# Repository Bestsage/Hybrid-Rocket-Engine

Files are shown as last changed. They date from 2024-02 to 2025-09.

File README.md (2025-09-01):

# Hybrid Rocket Engine Demonstrator


[]()


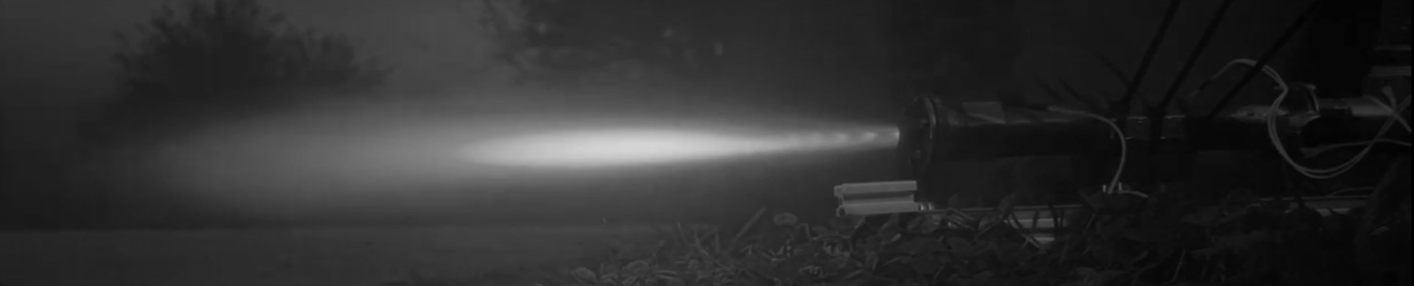
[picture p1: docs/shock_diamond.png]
Test firing with shock diamonds


## Table of Contents
- [Overview](#overview)
- [Abstract](#abstract)
- [Technical Specifications](#technical-specifications)
- [Test Results Gallery](#test-results-gallery)
- [Versioning System](#versioning-system)
- [Key Features](#key-features)
- [Repository Contents](#repository-contents)
- [Safety Considerations](#safety-considerations)
- [How to Use This Repository](#how-to-use-this-repository)
- [Citation](#citation)
- [Authors](#authors)
- [License](#license)

## Overview
This repository documents the **design, construction, and testing** of a **hybrid rocket engine demonstrator**, developed as part of our *Travail de maturité* and presented at the **Swiss National Contest**.  

Hybrid propulsion combines a **liquid oxidizer** with a **solid fuel grain**, offering a **middle ground** between:
- Simplicity and accessibility of **solid rockets**
- Performance and controllability of **bi-liquid engines**

Our objective:  
👉 Build a **reliable, efficient engine** with limited resources, able to theoretically propel a model rocket.

---

## Abstract
Over 9 months, we applied an **iterative engineering process**:  
- **Design**: CAD modeling (Fusion 360), rendering (Blender), combustion simulations (RocketCEA).  
- **Construction**: Machined steel combustion chamber, graphite nozzle, ABS/ASA fuel grains.  
- **Instrumentation**: Custom-built static test bench with Arduino-based data acquisition (thrust, pressure, temperature).  
- **Testing**: 18 static firings, continuously improving injector design, nozzle geometry, and fuel formulation.  

**Results**:  
- Stable thrust plateau of **26 N** (peak **40.4 N**) during 5-second burns  
- Combustion chamber pressure remained constant  
- Temperature < **150 °C** (no thermal risk observed)  
- **16 out of 18 successful tests** → high system reliability  
- Supersonic exhaust confirmed (visible shock diamonds)  

These results confirm that **hybrid propulsion is a viable option for model rocketry**, balancing performance, cost, and safety.

---

## Technical Specifications

### Engine Performance (Latest Configuration: V3-3-1)
| Parameter | Value | Unit |
|---|---|---|
| **Maximum Thrust** | 40.42 | N |
| **Average Thrust** | 26.02 | N |
| **Burn Time** | 5.0 | seconds |
| **Total Impulse** | 130.09 | N⋅s |
| **Specific Impulse** | 38.94 | seconds |
| **Chamber Pressure** | 5.31 (avg), 8.35 (max) | bar |

### Physical Specifications
| Component | Specification |
|---|---|
| **Combustion Chamber** | Machined steel, custom design |
| **Nozzle** | Graphite, throat diameter 5mm, exit 24mm |
| **Fuel Grain** | ABS/ASA plastic, star-shaped geometry |
| **Oxidizer** | Gaseous oxygen at 9 bar |
| **Injector** | Custom 3.5mm diameter orifice |

### Test Configuration
- **Fuel Mass**: 46g initial, 34g consumed (73.9% burn efficiency)
- **O/F Ratio**: 9.0:1 (oxygen to fuel)
- **Operating Temperature**: <150°C (safe thermal limits)
- **Success Rate**: 89% (16/18 successful tests)

---

## Test Results Gallery

### Performance Data by Version
- **[Version 1 Tests](docs/v1/)** - Initial proof of concept
- **[Version 2 Tests](docs/v2/)** - Improved injector design  
- **[Version 3 Tests](docs/v3/)** - Optimized nozzle geometry

### Key Test Results
| Test ID | Thrust (N) | Burn Time (s) | Chamber Pressure (bar) | Status |
|---|---|---|---|---|
| V3-1-1 | 10.65 peak | 5.0 | 6.76 max | ✅ Success |
| V3-1-2 | TBD | TBD | TBD | ✅ Success |
| V3-2-1 | 39.75 peak | 5.0 | 8.60 max | ✅ Success |
| V3-3-1 | 40.42 peak | 5.0 | 8.35 max | ✅ Success |

*Note: Each test folder contains detailed telemetry data (.TXT), analysis spreadsheets (.xlsx), temperature plots (.png), and test videos (.MOV)*

---

## Versioning System
All engine prototypes and test runs were indexed as:

VX-Y-Z

  - **X** = Major version (nozzle/injector redesign, new chamber)  
  - **Y** = Minor variant (fuel grain geometry, material)  
  - **Z** = Test number of that configuration  

Example: `V3-1-2` → Engine Version 3, first minor variant, second test.

---

## Key Features
- 🔧 **Custom static test stand**  
- 📈 **Arduino Nano + sensors** for thrust, chamber pressure, temperature  
- ♻️ **Iterative development cycle** (SpaceX-inspired approach: "Test, Fail, Fix, Repeat")  
- 🧪 **Supersonic flow** proven with visible shock diamonds  

---

## Repository Contents
- 📊 `NW25-643729_Finale_Arbeit.pdf` → **Full technical paper** (108 pages with detailed methodology, results, and analysis)  
- 📂 `docs/shock_diamond.png` → Supersonic exhaust visualization showing shock diamonds
- 📂 `docs/v1/` → Version 1 test data (initial proof of concept)
- 📂 `docs/v2/` → Version 2 test data (improved injector design)  
- 📂 `docs/v3/` → Version 3 test data (optimized performance)

### Test Data Structure
Each test folder (`docs/v{X}/v{X}-{Y}/v{X}-{Y}-{Z}/`) contains:
- **Raw telemetry**: `.TXT` files with time-series sensor data
- **Analysis**: `.xlsx` spreadsheets with calculated performance metrics  
- **Visualizations**: `.png` graphs showing thrust, pressure, and temperature
- **Documentation**: Test footage in `.MOV` format

---

## Safety Considerations

⚠️ **IMPORTANT SAFETY NOTICE** ⚠️

This project involves high-pressure systems, combustible materials, and rocket propulsion. **DO NOT attempt to replicate without proper safety training and supervision.**

**Safety measures implemented:**
- Static test stand with blast shields
- Remote ignition and data acquisition
- Fire suppression equipment on-site
- Proper ventilation and outdoor testing
- Personal protective equipment (PPE)
- Emergency shutdown procedures

**For educational use only** - This documentation is provided for learning purposes. Always consult with professionals and follow local regulations before conducting any rocket engine testing.

---

## How to Use This Repository

### Understanding the Test Data
1. **Navigate to test folders**: `docs/v{version}/v{version}-{variant}/v{version}-{variant}-{test}`
2. **Key files in each test folder**:
   - `.TXT` files: Raw sensor data (time, temperature, pressure, thrust)
   - `.xlsx` files: Processed data and analysis
   - `.png` files: Performance graphs and temperature plots
   - `.MOV` files: High-speed test footage
   - `*-output.txt`: Summary results and calculated performance metrics

### Analyzing Performance Data
- Thrust measurements in Newtons (N) and equivalent mass (kg)
- Chamber pressure in bar and Pascals
- Temperature monitoring at multiple points
- Burn time and total impulse calculations
- Fuel consumption and efficiency metrics

### Academic Research
This work represents a comprehensive study of hybrid rocket propulsion suitable for:
- University-level aerospace engineering courses
- High school physics and chemistry demonstrations
- Research into hybrid propulsion systems
- Model rocketry safety and performance analysis

---

## Citation

If you use this work in academic research or educational materials, please cite:

```
Bumann, S., & Gebhard, S. (2024). Hybrid Rocket Engine Demonstrator: 
Design, Construction, and Testing. Swiss National Contest - Travail de maturité. 
Gymnase de Morges. Retrieved from https://github.com/Bestsage/Hybrid-Rocket-Engine
```

**Academic Paper**: The complete 108-page technical documentation is available in `NW25-643729_Finale_Arbeit.pdf`

---

## Authors
- **Sacha Bumann**  
- **Samuel Gebhard**  

With the support of:  
- *Gymnase de Morges*
- dr. Ricardo Perez 
- prof. Gabriel Paciotti
- Daniel Gebhard
---

## License
This repository is provided for **educational and research purposes**.  
Feel free to explore, learn, and build upon our work 🚀

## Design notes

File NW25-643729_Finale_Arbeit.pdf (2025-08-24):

## Travail du concours national

### Conception et construction d’un démonstrateur de

# MOTEUR

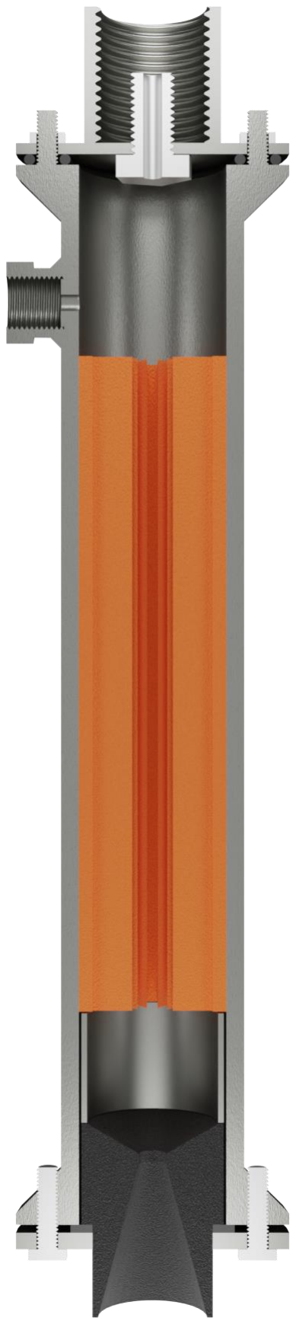
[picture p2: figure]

# FUSEE HYBRIDE

## Sacha Bumann, 3M05 Samuel Gebhard, 3M05

### Enseignant, Mr Ricardo Perez Suarez Expert de Science et jeunesse : Prof. Gabriel Paciotti

### Gymnase de Morges, avril 2025

2024 | II | Gymnase de Morges

2024 | III | Gymnase de Morges

Illustration page de titre : Rendu 3D du moteur V2 - réalisé avec le logiciel Blender.

# Remerciements

Nous tenons à exprimer notre profonde gratitude à toutes les personnes qui ont contribué à la réalisation de ce travail de maturité.

Tout d'abord, un grand merci à Ricardo Perez Suarez, notre professeur, qui nous a accompagnés tout au long de ce projet.

Tous nos remerciements vont également à Gabriel Paciotti, professeur à l’HES SO à Sion, pour nous avoir suivi lors de la suite de notre projet au concours national.

Nous souhaitons également remercier Daniel Gebhard, le grand-père de Samuel, pour son aide inestimable à son atelier, qui a été essentielle à notre avancement.

Nous exprimons également notre reconnaissance à Florent Gaspoz et à toute l’EPFL Rocket Team pour leurs précieux conseils.

Nous remercions nos relecteurs, Isabelle Bumann, Waltraud Deutsch, Annick Gebhard et Marjutta Ueberschlag pour leurs commentaires constructifs et leur précieuse aide dans la finalisation de ce travail.

Nous souhaitons exprimer notre gratitude envers nos familles et nos amis pour leur soutien constant et leurs encouragements tout au long de ce projet.

Et finalement, merci à la troisième loi de Newton, ayant rendu ce travail possible.

Un immense merci à tous ceux ayant contribué de près ou de loin à ce magnifique travail.

2024 | IV | Gymnase de Morges

# Résumé

Depuis notre plus jeune âge, nous avons toujours été passionnés par l'exploration spatiale et l'idée de quitter notre planète pour voyager dans un univers infini. Notre intérêt pour l'exploration spatiale nous a amenés à nous intéresser aux technologies la rendant possible, telles que les fusées et leurs moteurs surpuissants. Avant de proposer un travail de maturité, nous nous sommes initiés à la discipline de l’astromodélisme – consistant à construire de petits modèles de fusées pour les faire voler – en débutant la conception d’une mini-fusée propulsée par des moteurs disponibles en commerce.
Cependant, utiliser des moteurs préfabriqués n’égalait pas le désir d’en construire un soi-même. En étudiant les différents types de propulsion de moteur-fusée, la propulsion dite hybride nous a intrigués. Cette dernière, mélangeant un oxydant liquide et un combustible sous forme de bloc solide, incluait les avantages de la propulsion biliquide, où l’oxydant et le combustible sont liquides, et ceux de la propulsion solide, où un mélange des deux est stocké solidement. Il s’agissait là d’un juste milieu peu étudié entre complexité et performance. L’idée nous est venue d’en faire notre travail de maturité. Cela représentait une occasion parfaite de faire de ce travail un projet passionnant et riche en apprentissages. Dû aux restrictions sur les fusées artisanales, le projet fut d’uniquement concevoir et construire un moteur-fusée à propulsion hybride, théoriquement capable de propulser une fusée. L’entièreté des tests fut statique, le moteur étant solidement attaché au sol.
Après avoir étudié les risques de ce travail et déterminé les mesures de sécurité en conséquence, nous avons débuté la conception du banc de test. Ce dernier avait pour but de maintenir le moteur durant les tests, tout en récoltant suffisamment de données afin d’en analyser ses performances. Un système d’acquisition de données basé sur un Arduino Nano et des capteurs électroniques fut développé et programmé. Nous avons ensuite débuté la conception de la version initiale du moteur en fixant ses objectifs et ses contraintes. Après avoir étudié chaque partie de la construction d’un moteur de ce type, nous avons construit la chambre de combustion, l’injecteur d’oxydant, les blocs de carburant et la tuyère afin d’obtenir une première version de notre projet. Celle-ci avait pour but de déterminer la faisabilité du projet et d’établir une première idée de ce qui était possible. Après des tests particulièrement concluants, le moteur fut continuellement développé, toujours dans le but de le rendre plus performant et de se rapprocher des objectifs.
Au terme de ce travail, nous avons mis au point une version finale du moteur, avec laquelle nous avons procédé à quatre tests ayant révélé des performances considérables. Lors de l’un d’eux, nous avons atteint une force de poussée de plus de 40 newtons, le rendant aisément capable de soulever sa propre masse. En concevant et construisant un moteur-fusée à propulsion hybride fiable, performant et capable de théoriquement propulser une mini-fusée, nous avons accompli les objectifs fixés et démontré que la propulsion hybride est une alternative viable en astromodélisme.
Ce travail nous a permis de mettre un premier pied dans le domaine passionnant qu’est la propulsion spatiale et d’en apprendre ses fondements.

2024 | V | Gymnase de Morges

# Table des matières

2024 | VI | Gymnase de Morges
9. Version finale V3 | 53
9.1 | Changements apportés | 53
9.2 | Résultats finaux | 53
10. Conclusion | 64
10.1 Synthèse des résultats | 64
10.2 Synthèse des objectifs initiaux | 64
10.3 Suite éventuelle | 65
10.4 Mot de fin | 69
11. Table des illustrations | 70
12. Annexes | 71
13. Bibliographie | 90

2024 | VII | Gymnase de Morges

# Glossaire

ABS : acrylonitrile butadiène styrène, matière plastique imprimable en 3D
ASA : acrylonitrile styrène acrylate, matière plastique imprimable en 3D
Astromodélisme : discipline de loisir qui a pour but de concevoir et de faire voler des modèles réduits de fusées.
Banc de test : structure utilisée pour attacher le moteur et mesurer ses caractéristiques.
CC : chambre de combustion d’un moteur
Ergol : substance servant à la combustion du moteur (carburant ou oxydant)
Grain : bloc stocké dans le moteur utilisé comme carburant.
Impulsion spécifique : unité de mesure utilisée dans la conception d’un moteur à réaction afin de quantifier son efficacité en comparant sa force de poussée avec la quantité d’ergols consumés. Microcontrôleur : composant électronique miniature programmable composé d’un circuit intégré capable d’exécuter diverses tâches.
PETG : polyéthylène téréphtalate glycol, matière plastique imprimable en 3D dérivée du PET PLA : acide polylactique, matière plastique imprimable en 3D
Propergol : regroupement d’un ou plusieurs ergols stockés séparément ou ensemble. Tuyère : col à l’arrière du moteur destiné à accélérer les gaz issus de la combustion.

2024 | VIII | Gymnase de Morges

# Symboles utilisés

Nom | Description | Unité
ae | Vitesse du son à la sortie de la tuyère | m · s
| | -1
Ae | Aire de la section de la tuyère à sa sortie | m²
Ath | Aire de la section de la tuyère au col | m ²
CF | Coefficient de la poussée | -
F | Poussée du moteur | N
Favg | Poussée moyenne du moteur sur la durée d’un test | N
g | Accélération gravitationnelle au niveau de la mer | m · s
| | -2
Isp | Impulsion spécifique du moteur | s
Itot | Impulsion totale du moteur | Ns
ṁ | Débit massique dans le moteur | m³ · s⁻¹
Me | Nombre de mach à la sortie de la tuyère | -
ηCF | Efficacité de la tuyère | -
O/F | Rapport de mélange de l’oxydant et du carburant | -
Pa | Pression ambiante | Pa
Pc | Pression dans la chambre de combustion | Pa
Pe | Pression à la sortie de la tuyère | Pa
Rs | Constante spécifique d’un/de gaz parfaits | J · K⁻¹ · kg⁻¹
R | Constante universelle des gaz parfaits | J · mol⁻¹ K⁻¹
tburn | Durée de la combustion d’un test | s
Te | Température des gaz à la sortie de la tuyère | K
ve | Vitesse des gaz à la sortie de la tuyère | m · s⁻¹
γ | Indice adiabatique des gaz de combustion | -
ρe | Densité des gaz à la sortie de la tuyère | kg · m⁻³

2024 | IX | Gymnase de Morges

Moteur-fusée hybride

2024 | 1 | Gymnase de Morges

# 1. Introduction

# 1.1 Contexte et motivation

Depuis notre plus jeune âge, nous avons tous les deux toujours été passionnés par l’espace. L’idée de quitter notre planète et de voyager dans un inconnu disproportionné nous fascinait. Dans ce vide infini, chacune des distances ou temporalités semblait gigantesque à côté de ce qui nous était connu. Nous nous intéressions aux progrès accomplis, aux missions en cours, aux projets futuristes et rêvions toujours d’en connaitre davantage sur ce sujet.
Bien évidemment, notre passion pour l’exploration spatiale nous incita à nous intéresser aux technologies la rendant possible, telles que le fonctionnement des fusées ainsi que de leurs moteurs surpuissants. Les domaines techniques nous ayant déjà toujours intéressés, nous ressentions le désir de mieux comprendre les technologies utilisées dans l’aérospatiale. Cependant, comprendre les innovations mises au point par des entreprises aux budgets disproportionnés n’était pas comparable au fait de construire de nous-mêmes, et à notre échelle, de tels engins. Bien avant les propositions de travaux de maturité, l’idée nous était venue de débuter dans la discipline dite « d’astromodélisme » consistant à construire des modèles réduits de fusées dans le but de les faire voler.
Nous avons alors entrepris l’élaboration d’une fusée expérimentale de petite taille, propulsée par des moteurs solides disponibles dans le commerce de la marque Klima GmbH. Cette fusée aurait dû, selon des simulations logicielles, atteindre une altitude proche de 300 m. Ce projet, pour le moment inachevé par manque de temps, fit naître en nous d’autres idées.
L’une d’entre elles fut d’utiliser, à la place de moteurs du commerce, notre propre moteur fait maison dans l’objectif d’obtenir de meilleures performances et plus de liberté. Motivés, nous avons commencé à nous renseigner sur la propulsion à combustion via le contenu que nous pouvions trouver en ligne. Plus nous en apprenions, plus ce processus de fabrication interdisciplinaire, mélangeant physique des matériaux, dynamique des fluides, thermodynamique et réactions chimiques nous fascinait. Quand le choix des travaux de maturité (que nous appellerons TM) approcha, nous vîmes en cela l’occasion idéale d’en construire un. C’était là l’occasion de travailler sur le sujet qui nous passionnait et que nous savions suffisamment intéressant pour nous motiver durant les neuf mois que devait durer le travail.

2024 | 2 | Gymnase de Morges

# 1.2 Problématique

Aujourd’hui, les fusées utilisent principalement 3 types de moteur.
1 | L’astromodélisme utilise principalement des moteurs disponibles dans le commerce
| pour leur simplicité et leur fiabilité. Cependant ces moteurs à combustion dite solide,
| où le propergol est stocké sous forme d’un bloc solide, sont souvent peu performants.
2 | La construction de moteurs plus performants, à combustion principalement dite
| biliquide, où les deux ergols sont stockés séparément et sous forme liquide, est
| cependant complexe et coûteuse. Ils sont donc principalement réservés au domaine
| professionnel pour des projets de bien plus grande ampleur.
3 | Dans le but de trouver un compromis entre performances, complexité et coût, nous
| allons nous intéresser à un troisième type de propulsion dite hybride. Dans ces
| moteurs-ci, un des ergols, majoritairement le carburant, est stocké sous la forme d’un
| bloc solide, et l’autre ergol sous forme fluide (liquide ou gazeux). Ce type de moteur
| est très peu utilisé dans l’astromodélisme et dans les projets spatiaux et apporte ainsi
| un intérêt particulier à ce travail.
L’objectif de ce travail fut donc le suivant :
Concevoir et construire un moteur-fusée expérimental performant et fiable capable de théoriquement propulser une fusée expérimentale.
Nous voulions démontrer par la conception et la construction d’un moteur-fusée expérimental, la problématique suivante :
L’utilisation de moteur-fusée à propulsion hybride est-elle adaptée pour la conception de fusées expérimentales d’astromodélisme ?
Afin de répondre à cette question générale, plusieurs sous-questions ont dû être préalablement soulevées :
1) Quels sont les principes fondamentaux de la propulsion hybride ?
2) Quels sont les risques à prendre en compte et comment les limiter ?
3) Comment concevoir une version initiale d’un moteur-fusée hybride ?

Par ce travail, nous souhaitions approfondir nos connaissances en propulsion spatiale et démontrer qu’il est possible, même à un niveau scolaire, de construire un moteur-fusée hybride performant et fiable. Nous souhaitions aussi explorer les avantages et les inconvénients de ce type de propulsion, moins étudié que ses concurrents, afin de déterminer si la propulsion hybride est compétitive ou non face à ses alternatives.

2024 | 3 | Gymnase de Morges

# 1.3 Historique

L’inconnu dans l’espace a toujours fasciné l’être humain. Dans l’objectif d’améliorer notre compréhension de l’environnement, l’univers nous entourant fut depuis toujours interrogé. C’est alors que l’idée de potentiellement explorer le vide de l’espace, les astres et tout ce qui nous paraît si petit - pourtant que nous savons si grand - est apparue. Dépassant les limites de nos capacités, cette exploration n’est longtemps restée qu’un rêve inatteignable. Par l’avancement technologique, ce rêve se transforma en concept rempli d’espoir déjà dès le début du XVIIIe siècle. En 1903, Constantin Tsiolkovski, scientifique russe et l’un des premiers théoriciens de l’aérospatiale, publia l’ouvrage « L’Exploration de l’espace cosmique par des engins à réaction »
1
Ce dernier évoque l’idée de voyage cosmique à l’aide de propulsion dite à réaction. Tsiolkovski évoque notamment l’utilisation de propergols liquides ou encore de fusées à étages. Cette idée ne fut malheureusement pas réalisée tout de suite, de par l’absence de technologies nécessaires. Cependant, Tsiolkovski demeura un pionner dans l’avancée de l’exploration spatiale.
Lors des deux guerres mondiales qui suivirent respectivement en 1914 et en 1939, les intérêts du développement changèrent et la nécessité d’armes balistiques, entre autres, surpassa la simple curiosité spatiale. L’idée d’armes intercontinentales voyageant à vitesse supersonique terrifiait tout autant qu’elle réjouissait. Dans des intérêts militaires et économiques, de tels engins procureraient à ceux les possédant une supériorité immédiate et l’espoir d’une victoire. Les intérêts scientifiques devinrent militaires et le développement technologique avança plus vite que jamais. Le V2 allemand, conçu principalement par l’ingénieur Werner von Braun, fut le premier missile balistique fonctionnel lors de son déploiement en 1944. Ce moteur à combustion biliquide représentait une prouesse majeure atteignant cinq fois la vitesse du son.
La guerre froide accéléra encore davantage la recherche sur les technologies balistiques et les premiers missiles capables de transporter des ogives nucléaires, tel que le R-7 soviétique, firent leurs premières démonstrations terrifiantes. L’idée de sécurité sur son propre territoire disparut et la menace constante prit sa place. En parallèle, la conquête spatiale devint un nouveau front militaire et les exploits se succédèrent. L’astronaute soviétique Yuri Gagarine effectua le premier vol spatial en 1961. En 1969, Neil Armstrong, astronaute américain à bord du lanceur Saturn V, posa son pied sur notre satellite naturel, la Lune. Dans cette guerre où l’on voulait posséder le ciel, des budgets colossaux furent investis par les états dans la recherche spatiale. En 1967, 3.45% des dépenses des USA, soit près de 50 milliards de dollars, furent investis dans la NASA²
Les missions Apollo vers la Lune se succédèrent par la suite.

1 Constantin Tsiolkovski [en ligne]. [S. l.] : [s. n.], 9 juillet 2024. [Consulté le 24 août 2024]. Disponible à l’adresse : https://fr.wikipedia.org/w/index.php?title=Constantin_Tsiolkovski&oldid=216658015. Page Version ID: 216658015. Constantin Tsiolkovski [en ligne]. [S. l.] : [s. n.], 9 juillet 2024.
[Consulté le 24 août 2024]. Disponible à l’adresse : https://fr.wikipedia.org/w/index.php?title=Constantin_Tsiolkovski&oldid=216658015. Page Version ID: 216658015.
2 Budget of NASA [en ligne]. [S. l.] : [s. n.], 4 juillet 2024. [Consulté le 4 juillet 2024]. Disponible à l’adresse : https://en.wikipedia.org/w/index.php?title=Budget_of_NASA&oldid=1232557630. Page Version ID: 1232557630. Budget of NASA [en ligne]. [S. l.] : [s. n.], 4 juillet 2024.
[Consulté le 4 juillet 2024]. Disponible à l’adresse : https://en.wikipedia.org/w/index.php?title=Budget_of_NASA&oldid=1232557630. Page Version ID: 1232557630.

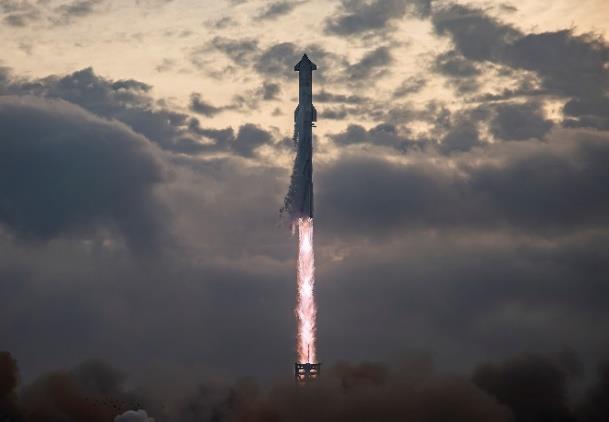
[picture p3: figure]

2024 | 4 | Gymnase de Morges

Dès lors, le progrès spatial continue à se développer et particulièrement depuis ces dernières années avec l’arrivée d’entreprises privées telles que celle du multimilliardaire Elon Musk, SpaceX, dans le domaine de l’aérospatiale. Nous pouvons citer le lanceur Falcon 9 de SpaceX, ayant déjà révolutionné la mise en orbite de satellites, en offrant un lanceur partiellement réutilisable. Citons encore le projet innovant « StarShip » et son booster nommé « SuperHeavy », formant ensemble le plus grand et plus puissant lanceur jamais construit. Propulsé par 33 moteurs Raptor biliquides, le but de ce projet titanesque est principalement de rendre l’accès à l’espace moins cher grâce à un lanceur réutilisable.

# 2.Principes Fondamentaux

# 2.1 Principes de base des moteurs-fusées

Le fonctionnement des moteurs-fusées, faisant plus généralement partie de la famille des moteurs dits à réaction, est souvent mécompris voire incompris. Le principe de propulsion à réaction réside sur la notion physique de « conservation de la quantité de mouvement ». Le moteur à réaction tire son nom de la troisième loi de Newton, aussi appelée principe d’action-réaction, étant un cas spécial de la théorie de la conservation de la quantité de mouvement.

## Quantité de mouvement

La quantité de mouvement p⃗ d’un corps matériel désigne une grandeur vectorielle, relative à un référentiel choisi, représentant la « grandeur de mouvement » associée à un système. Elle est exprimée comme suit, tel que le produit de la masse du système par le vecteur vitesse de son centre d’inertie :

p⃗ = mv⃗ | (1)
Où p⃗ désigne le vecteur quantité de mouvement, m la masse du système et v⃗ le vecteur vitesse du centre d’inertie du système, soit la somme vectorielle des vecteurs vitesse associée à chacun des objets le composant.
Dans le cas d’un système isolé ou pseudo-isolé, cette quantité reste inchangée. On parle alors de conservation de la quantité de mouvement.
Analysons dans un jeu de billard, en négligeant les frottements et en considérant le mouvement des balles décrivant un MRU (mouvement rectiligne uniforme), un système composé de deux boules de masse identique dont l’une en mouvement. L’une d’entre elles percute l’autre à une vitesse donnée. Dans le cas d’un système pseudo isolé, l’entièreté de l’énergie de la première balle sera transmise à la seconde. La deuxième balle repartira ainsi à la même vitesse qu’allait la première, qui demeure à présent immobile. Il y a alors conservation de la quantité de mouvement dans le système comprenant les deux balles.

Figure 1 : Photo du vol N° 3 du StarShip -https://x.com/SpaceX/status/1768642869525725253/photo/2.

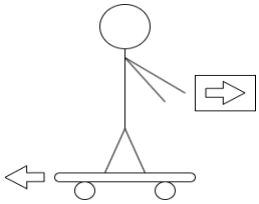
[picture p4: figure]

2024 | 5 | Gymnase de Morges

## Moteurs à réaction

Afin de mieux représenter le phénomène se produisant dans les moteurs à réaction, il est nécessaire de comprendre l’image suivante :
Considérons un skateur, debout sur sa planche et
immobile. Ce dernier lance alors sur un des côtés un bloc
de béton de masse importante qu’il tenait dans ses mains. Intuitivement, le skateur sera accéléré dans le sens opposé de celui où le bloc a été lancé. Ainsi, le mouvement du skateur est « dû » à la conservation de la quantité de mouvement dans le système incluant le skateur et le bloc. Cette quantité, nulle au départ, demeure ainsi puisque la somme des quantités de mouvements respectives au skateur et au bloc s’annule. Ceci est l’une des multiples manifestations de cette loi de
conservation au quotidien, que nous admettons sans en
interroger l’origine.
Dans le cas des moteurs à réaction, ce n’est pas un bloc qui est éjecté, mais un fluide à très grande vitesse pouvant être de nature très différente. Dans la majorité des moteurs, ces fluides sont le produit d’une combustion ayant eu lieu dans le corps du moteur, mais d’autre méthodes demeurent possibles. Citons par exemple les hydrojets, accélérant de l’eau ou encore la propulsion ionique et nucléaire que nous détaillerons ensuite.
Nous distinguons alors deux principaux types de moteurs à réaction ; d’un côté les moteurs dits « anaérobie » tel que les moteurs-fusées, où l’entièreté des fluides éjectés ou source de ces fluides - soit l’oxydant et le carburant pour les moteurs à combustion - sont tous stockés dans le corps de l’appareil. De l’autre côté, nous distinguons les moteurs dits « aérobie » pour lesquels un ou plusieurs fluides sont pris de l’environnement et non stockés dans le corps de l’appareil. Il s’agit notamment des hydrojets, des turbopropulseurs et turboréacteurs d’avion, pour lesquels l’air servant d’oxydant est aspiré à l’avant de l’engin.

## Quantité de mouvement dans les moteurs-fusées

Considérons alors une fusée, immobile dans le vide spatial par rapport à un référentiel donné. Le système étudié est constitué de la fusée ainsi que des propergols stockés. Sa quantité de mouvement, étant le produit de sa masse par le vecteur vitesse de son centre d’inertie, est alors nul. Nous avons ainsi l’équation suivante.

p⃗totale = mtotalev⃗initiale = 0⃗⃗ | (2)
Où p⃗totaledésigne la quantité de mouvement de l’entièreté du système incluant la fusée ainsi que les propergols stockés dedans, mtotale la masse de la fusée ainsi que des propergols et v⃗initiale la vecteur vitesse du centre d’inertie de la fusée, ici le vecteur nul.
Une fois le moteur allumé, d’énormes quantités de gaz sont accélérés à des vitesses supersoniques et sont éjectés à l’arrière du moteur. Le vecteur vitesse du centre d’inertie de la fusée s’oriente à l’opposé de celui des gaz éjectés et la fusée est accélérée.

Figure 2 : Illustration de l'image du skateur -réalisée avec Diagrams.net.
En lançant le bloc vers la droite, le skateur est accéléré vers la gauche.

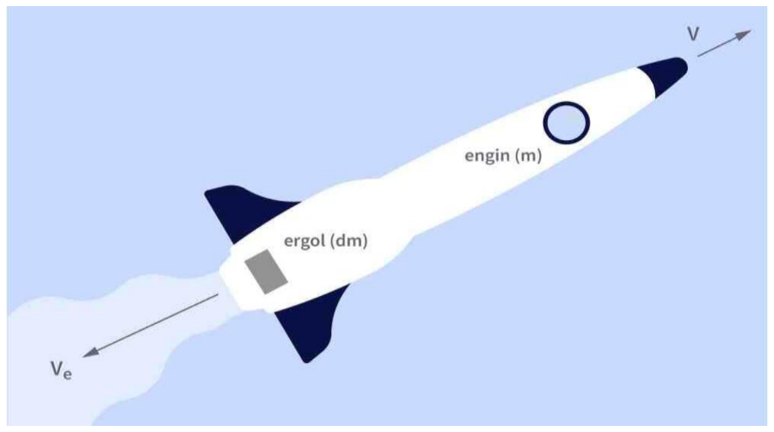
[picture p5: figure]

2024 | 6 | Gymnase de Morges

Nous avons ainsi les égalités suivantes :

p⃗initiale = p⃗finale | (3)

0⃗⃗ = mfuséev⃗⃗fusée + mpropergolsv⃗⃗propergols

L’accélération de la fusée indique donc la présence d’une force appliquée à la fusée, orientée dans le même sens que le vecteur v⃗fusée

, soit
vers l’avant. Le vecteur de cette force, appelé « poussée » ou « thrust » en anglais, correspond à la dérivée de la quantité de mouvement de la fusée sur le temps, soit l’opposé de celle des propergols éjectés :

F⃗ =

dp⃗fusée
dt = −

dp⃗propergols
dt | (4)

F⃗ correspond au vecteur force de la poussée, p⃗fusée
la quantité de mouvement de la fusée vide, p⃗propergols la quantité de mouvement des gaz de combustion éjectés et t le temps. En considérant que la quantité de mouvement est le produit de la masse par la vitesse, la poussée peut s'écrire :

F =

dp⃗
dt =

dve
dt ∙ m +

dm
dt ⋅ ve → F =

dm
dt ⋅ ve

La vitesse d'éjection des gaz ve est supposée constante pour simplifier le modèle. La valeur de cette poussée peut donc être calculée selon l’équation scalaire suivante :

F = ṁ ve

(5)
Où F est la poussée du moteur en newtons (N), ṁ le débit massique de gaz à la sortie du moteur en kilogrammes par seconde (kg/s) - ainsi égal selon la conservation du débit massique lors de la combustion à la somme du débit massique des différents propergols - et finalement ve

la vitesse
d’éjection des gaz à la sortie du moteur en mètres par seconde (m/s). La valeur de cette poussée est alors égale à la différence de quantité de mouvement par seconde de la fusée. Nous verrons une version plus détaillée de cette équation dans le chapitre sur la conception de la tuyère (cf. section 7.2.5).
Afin de produire ces gaz à très haute vitesse, un moteur-fusée détend les gaz chauds à haute pression produits par la combustion pour les accélérer. Cette énergie thermique est alors convertie en énergie cinétique distribuée aux gaz éjectés ainsi qu’à la fusée. Finalement, nous comprenons qu’afin d’augmenter la poussée d’un moteur, il est nécessaire de maximiser le débit massique de gaz à la sortie, ainsi que sa vitesse d’éjection.

Figure 3 : Illustration de la fusée -https://www.numworks.com/fr/professeurs/activites-pedagogiques/terminale/rocket-equation/.

2024 | 7 | Gymnase de Morges

Un moteur plus puissant produit ainsi plus de gaz et les éjecte plus rapidement. A titre d’exemple, le moteur SpaceX Raptor V3³

, moteur propulsant le vaisseau StarShip ainsi que son lanceur SuperHeavy, produit près de 2600 kN de poussée en éjectant les gaz de combustion à environ trois fois la vitesse du son, soit environ 3'600 km/h.

# 2.2 Qu’est-ce qu’un bon moteur ?

Dans le but de critiquer par la suite notre moteur, nous avons dû définir ce que représentait un bon moteur.

### 1. Performances

Les performances d’un moteur-fusée sont définies par plusieurs paramètres clés :
- Impulsion spécifique (Isp) : un bon moteur doit maximiser cet indice pour obtenir une meilleure efficacité énergétique.
- Rapport poussée/poids : un moteur performant doit délivrer une poussée élevée tout en restant aussi léger que possible. Pour ce travail, cette optimisation de masse ne sera pas recherchée.
- Fiabilité de l’allumage et de la combustion : une combustion stable est essentielle pour garantir une poussée constante et éviter les risques d’explosion.

### 2. Complexité

Un bon moteur-fusée doit trouver un équilibre entre sophistication et simplicité pour être fonctionnel :
- Nombre de pièces et maintenance : moins un moteur a de composants, plus il est facile à concevoir et à entretenir. « Les pièces inexistantes n’échouent jamais ».
- Gestion thermique : un bon moteur doit minimiser les besoins en refroidissement actif ou utiliser des matériaux résistants aux hautes températures pour réduire la complexité du système.

### 3. Durabilité

La durée de vie d’un moteur-fusée et sa réutilisabilité dépendent de plusieurs éléments :
- Matériaux résistants : l’utilisation de matériaux durables, résistant à l’érosion, et à la fragilisation rendent le moteur durable.
- Capacité à supporter plusieurs cycles : un moteur réutilisable doit pouvoir encaisser plusieurs allumages et vols sans nécessiter de réparations majeures.
- Stabilité structurelle : un bon moteur doit être capable d’encaisser des vibrations, des contraintes mécaniques et thermiques sans risque de défaillance prématurée.

3 SpaceX Raptor [en ligne]. [S. l.] : [s. n.], 30 juin 2024. [Consulté le 4 juillet 2024]. Disponible à l’adresse : https://en.wikipedia.org/w/index.php?title=SpaceX_Raptor&oldid=1231786692. Page Version ID: 1231786692.

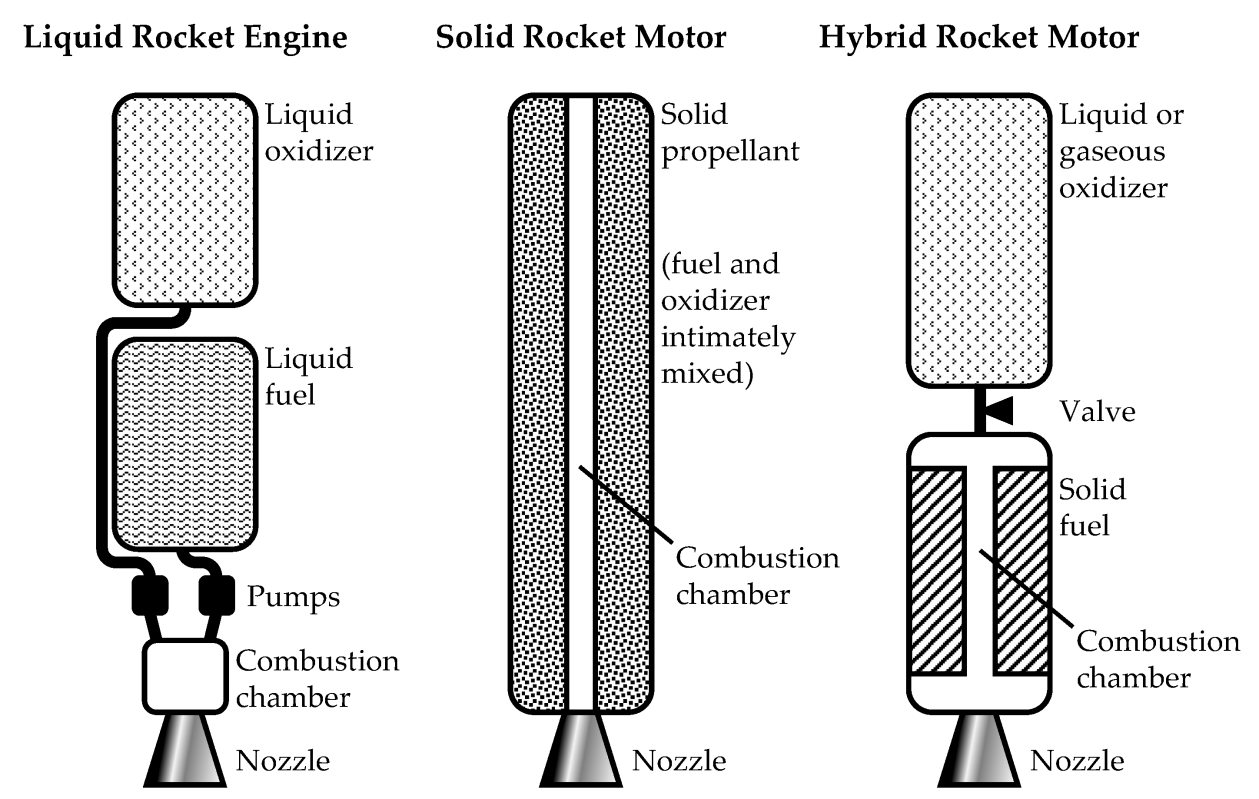
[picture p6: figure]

2024 | 8 | Gymnase de Morges

# 2.3 Différents types de moteurs-fusées

Les moteurs-fusées sont classés en différentes catégories suivant leur mode de fonctionnement.

## Les propulseurs chimiques

Ces moteurs appartenant à la famille la plus répandue, fonctionnent à l’aide de réactions chimiques produisant des gaz chauds à haute pression qui seront ensuite accélérés au travers d’une tuyère. On peut diviser cette famille en trois sous-catégories :

Figure 4 : Différents types de moteurs-fusées à propulsion chimique - https://www.mdpi.com/energies/energies-14-06794/article_deploy/html/images/energies-14-06794-g001.png.

Légende :
a. Moteur-fusée liquide (Liquid Rocket Engine)
- Oxydant liquide (Liquid oxidizer)
- Combustible liquide (Liquid fuel)
- Pompes (Pumps)
- Chambre de combustion (Combustion chamber)
- Tuyère (Nozzle)
b. Moteur-fusée solide (Solid Rocket Motor)
- Propergol solide (Solid propellant)
- Chambre de combustion (Combustion chamber)
- Tuyère (Nozzle)
c. Moteur-fusée hybride (Hybrid Rocket Engine)
- Oxydant liquide ou gazeux (Liquid or gaseous oxidizer)
- Vanne (Valve)
- Combustible solide (Solid fuel)
- Chambre de combustion (Combustion chamber)
- Tuyère (Nozzle)

2024 | 9 | Gymnase de Morges

## a) Propulseur à propergol solide

### Principe de fonctionnement :

1. L'allumeur enflamme le propergol dans la chambre de combustion.
2. Le propergol brûle, produisant des gaz chauds à haute pression.
3. Les gaz chauds sont canalisés à travers la tuyère, où ils sont accélérés et détendus pour produire une poussée.
Les propulseurs à propergol solide sont dits « simples » et sont composés d’un mélange préformé d’oxydant et de carburant sous forme de poudre ou de solide. Ils sont très peu onéreux à la production, comparé à leur impressionnante capacité à produire de grandes poussées. Cependant, par leur simplicité, ils représentent un potentiel danger car le fait que les deux ergols soient déjà mélangés les rend impossibles à éteindre. On se souviendra des paires de propulseurs solides des six navettes spatiales américaines qui étaient responsables d’environ 85% de la poussée au décollage, mais qui entraineront la perte de l’équipage de la navette nommé Challenger4 en 1986.
Dans le monde des micro-fusées, ces propulseurs sont très appréciés car ils sont accessibles à l’achat et à prix réduit. Leur simplicité et le fait qu’ils nécessitent peu d’infrastructures (une mèche suffit) les rendentfacilement intégrables dans un projet. Finalement leur capacité à fournir une « poussée instantanée » permet d’arracher rapidement une micro-fusée à son pas de tir. D’ailleurs on retrouve aussi ces propulseurs dans les feux d’artifice.

## b) Propulseur à propergol liquide

Cette catégorie de moteur peut exister sous d’innombrables formes. La plus répandue vous est présentée ici :

### Principe de fonctionnement simplifié :

1. Les ergols cryogéniques sont acheminés vers les pompes et remplissent toute la tuyauterie qui refroidit.
2. Les vannes d’alimentation des pompes s’ouvrent et celles-ci commencent à fonctionner.
3. Quelques centièmes de secondes plus tard, les vannes principales du moteur s’ouvrent et les ergols sous haute pression (entre 50 et 700 bars) entrent dans la chambre de combustion via un injecteur. Dans ce même temps, l’allumeur démarre la combustion.
4. Les ergols brûlent entre eux et produisent des gaz chauds sous haute pression (entre 40 et 300 bars).
5. Les gaz chauds sont canalisés à travers la tuyère, où ils sont accélérés pour produire de la poussée.

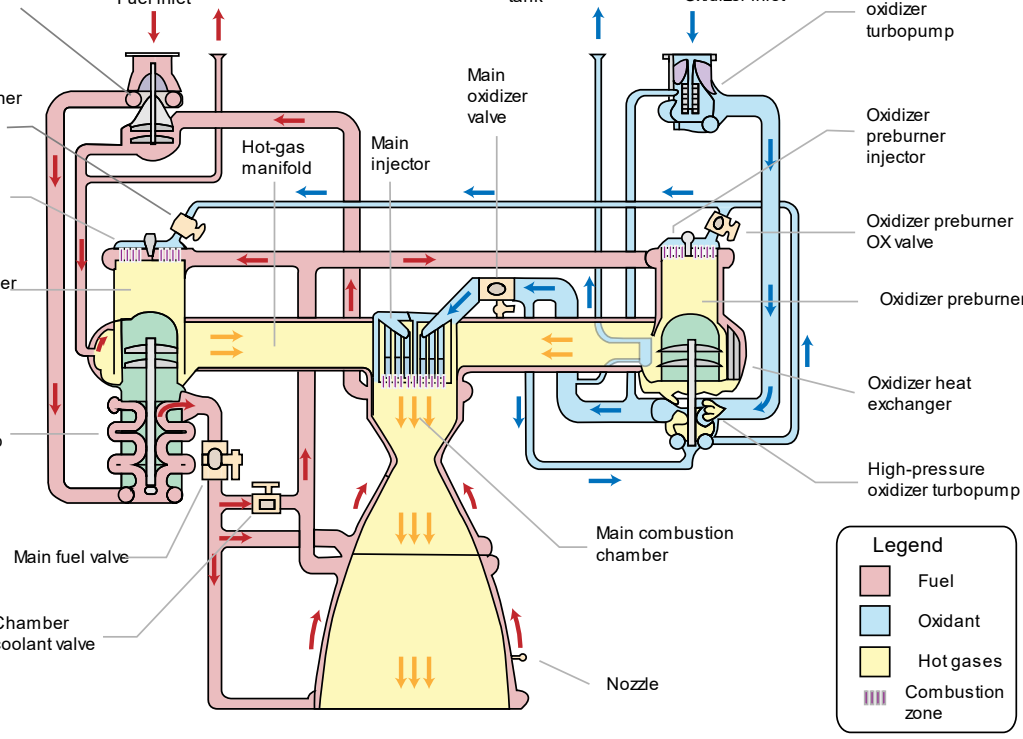
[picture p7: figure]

2024 | 10 | Gymnase de Morges

Les moteurs-fusées à ergols liquides sont les plus utilisés dans le marché des lanceurs. Ce sont les moteurs chimiques avec la plus grande impulsion spécifique : elle peut atteindre les 450 secondes pour le RS-25⁴

, moteur des navettes spatiales américaines et du lanceur SLS⁵

Leurs « carburants » étant stockés dans des réservoirs séparés, ces moteurs ont l’avantage d’être relativement simples à ravitailler en ergols durant un vol.
Cependant, ils ont le désavantage d’être extrêmement complexes. Le schéma ci-dessus ainsi que le principe de fonctionnement déjà expliqué sont simplifiés à l’extrême, car ce sont les pompes qui doivent performer et ce à des températures et pressions extrêmes, plusieurs tonnes d’ergols par seconde. Or, ces moteurs ont un nombre important de vannes, de tuyauterie et de capteurs nécessaires afin d’éviter une explosion ce qui les rend difficiles à miniaturiser.
Ci-dessous, le schéma de fonctionnement du moteur RS-25 démontre la complexité d’un tel moteur.

4 RS-25 [en ligne]. [S. l.] : [s. n.], 14 août 2024, p. 25. [Consulté le 25 août 2024]. Disponible à l’adresse : https://en.wikipedia.org/w/index.php?title=RS-25&oldid=1240226630. Page Version ID: 1240226630. RS-25 [en ligne]. [S. l.] : [s. n.], 14 août 2024, p. 25. [Consulté le 25 août 2024]. Disponible à l’adresse : https://en.wikipedia.org/w/index.php?title=RS-25&oldid=1240226630. Page Version ID: 1240226630.
5 Space Launch System [en ligne]. [S. l.] : [s. n.], 20 août 2024. [Consulté le 21 août 2024]. Disponible à l’adresse : https://en.wikipedia.org/w/index.php?title=Space_Launch_System&oldid=1241342181. Page Version ID: 1241342181. Space Launch System [en ligne]. [S. l.] : [s. n.], 20 août 2024.
[Consulté le 21 août 2024]. Disponible à l’adresse : https://en.wikipedia.org/w/index.php?title=Space_Launch_System&oldid=1241342181. Page Version ID: 1241342181.

Figure 5 : Schéma du moteur RS-25 - https://en.wikipedia.org/wiki/RS-25.

2024 | 11 | Gymnase de Morges

## c) Propulseurs Hybride

### Principe de fonctionnement :

1. Le réservoir d’oxydant est rempli.
2. Lorsque le moteur est mis à feu, l'allumeur pré-enflamme le carburant solide dans la chambre de combustion.
3. La vanne s'ouvre et l'oxydant s'écoule vers l'injecteur.
4. L'injecteur vaporise l'oxydant et le dirige dans la chambre de combustion.
5. L'oxydant et le carburant brûlent ensemble, produisant des gaz chauds à haute pression.
6. Les gaz chauds sont canalisés à travers la tuyère, où ils sont accélérés et détendus pour produire une poussée.
Les moteurs-fusées hybrides représentent une solution intermédiaire entre les moteurs à ergols solides et ceux à ergols liquides. Leur complexité, bien que plus grande que celle des moteurs à propergols solides, reste simple avec peu de pièces amovibles (uniquement la vanne principale normalement). Un de leurs avantages principaux est que les deux ergols sont stockés sous différents états physiques. Lors d’une rupture, les deux ergols ne peuvent donc que partiellement entrer en contact et brûler. Ils sont très peu représentés dans l’industrie de l’aérospatiale, néanmoins on notera que le SpaceShipTwo de Virgin Galactic en utilise un.

## Les autres types de propulseurs

## a) Les propulseurs ioniques :

Les moteurs de fusée à propulsion ionique utilisent une technologie de propulsion avancée qui utilise des ions pour générer de la poussée. Ils sont particulièrement adaptés aux missions spatiales à long terme et sont de plus en plus utilisés dans l'exploration spatiale. Un moteur ionique peut avoir une impulsion spécifique entre 3000 à 5000 secondes, contre 300 secondes en moyenne pour les moteurs chimiques. Ils sont capables de fonctionner pendant plusieurs milliers d'heures, offrant une propulsion continue sur de longues distances. Cependant ils n’offrent que de très faibles poussées, limitant leur usage aux objets en transit interplanétaire ou positionnés sur de hautes orbites.

### Principe de fonctionnement :

1. Ionisation : le moteur ionique commence par ioniser un gaz (souvent du xénon) en lui donnant une charge positive.
2. Accélération des ions : les ions positifs sont ensuite accélérés par un champ électrique intense généré par des électrodes.
3. Éjection des ions : les ions accélérés sont éjectés à grande vitesse, ce qui génère une poussée.

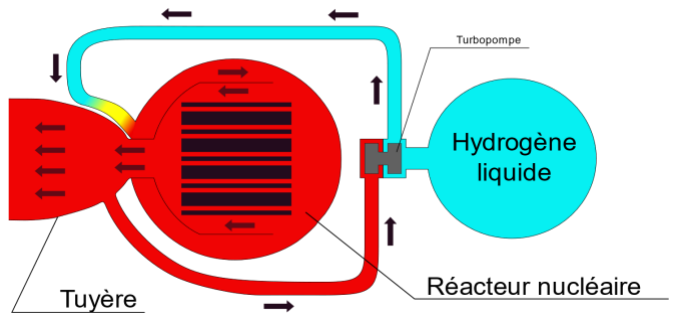
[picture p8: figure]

2024 | 12 | Gymnase de Morges
b) Les propulseurs nucléaires thermiques.

### Principe de fonctionnement :

1. Un fluide est chauffé par un
réacteur à fission nucléaire.
2. Une partie de ces gaz chauds est accélérée et détendue par une tuyère, l’autre dirigé vers une turbopompe pour pomper le
fluide dans le réacteur nucléaire. Dans ces moteurs, l’énergie vient de la fission nucléaire de combustible. Ceux-ci ont l’avantage d’être environ 10⁷ fois plus
denses | énergétiquement | que | les
combustibles des moteurs chimiques.
Les États-Unis et l’URSS ont développé de tels programmes lors de la guerre froide. Il y a par exemple le programme NERVA⁶ développé entre 1960 et 1972 dans le but d’atteindre Mars. Le programme a été arrêté pour cause budgétaire, il a néanmoins produit plusieurs prototypes et même des moteurs fonctionnels prêts à voler. Le prototype ultime était le moteur XE automatiquement démarré et régulé contenant tous les systèmes critiques.

# 2.4 Avantages et inconvénients des moteurs hybrides

Comme toute technologie, la propulsion hybride amène ses propres avantages et inconvénients. Les principaux sont cités ci-après.

## Avantages

- Premièrement, du point de vue de la complexité de construction, le moteur hybride est généralement plus simple que les moteurs liquides, du fait qu’il ne nécessite pas l’utilisation de turbopompe, complexe à produire. Il est toutefois plus complexe que les moteurs solides et présente ainsi un juste milieu intéressant dans la production de
| moteurs.
- Le moteur hybride possède une impulsion spécifique théorique supérieure aux moteurs solides, le rendant plus performant.
- La capacité de moduler l’injection d’oxydant lui offre la possibilité de contrôler sa poussée ainsi que d’arrêter et redémarrer sa combustion à plusieurs reprises. Ceci comme pour les moteurs liquides, ce qui le rend plus intéressant que les moteurs solides qui sont
| dépourvus de contrôle.

6 NERVA [en ligne]. [S. l.] : [s. n.], 8 août 2024. [Consulté le 27 août 2024]. Disponible à l’adresse : https://fr.wikipedia.org/w/index.php?title=NERVA&oldid=217506082. Page Version ID: 217506082. NERVA [en ligne]. [S. l.] : [s. n.], 8 août 2024. [Consulté le 27 août 2024]. Disponible à l’adresse : https://fr.wikipedia.org/w/index.php?title=NERVA&oldid=217506082. Page Version ID: 217506082.

Figure 6 : Schéma d'un moteur nucléaire thermique -https://fr.wikipedia.org/wiki/Propulsion_nucl%C3%A9aire_thermique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 mique%20ou,pouss%C3%A9e%20qui%20propulse%20la%20f us%C3%A9e.

2024 | 13 | Gymnase de Morges
- Du point de vue sécuritaire, les moteurs hybrides contiennent l’oxydant et le carburant séparément empêchant les risques de combustion involontaire lors de leur stockage. En effet, les moteurs solides sont propices à s’enflammer accidentellement et sont simplement inextinguibles, les rendant plus dangereux que leurs alternatives.
- Le carburant stocké solidement offre aussi la possibilité de bénéficier de la densité d’un ergol solide, tout en conservant les avantages de la propulsion liquide en utilisant un deuxième ergol fluide.

## Inconvénients

- Dû au mauvais contact thermique entre le bloc d’ergol et les gouttelettes d’oxydant vaporisé, la vitesse de régression du bloc d’ergol (vitesse à laquelle le bloc d’ergol est brulé) est trop faible pour ce type de moteur⁷

. Il s’agit alors du principal inconvénient de la propulsion hybride, limitant donc la vitesse de combustion et les performances qui en résultent. Ce problème peut être atténué en modifiant la structure du bloc d’ergol bien que cela diminue son volume.
- La propulsion hybride, tout comme la propulsion solide, offre difficilement une poussée stable dans le temps, étant donné l’agrandissement du volume de la chambre de combustion ainsi que la fluctuation de l’aire d’ergol solide au fur et à mesure de la combustion, modifiant ainsi la géométrie du bloc.
- La combustion de ces moteurs est animée par énormément d’instabilités dues aux natures différentes des ergols et à la complexité de la géométrie de la chambre de combustion évoluant pendant la combustion. Ces instabilités rendent ce type de combustion difficile à modéliser fidèlement et donc à prévoir leurs performances.
À cause des désavantages cités ci-dessus, la propulsion hybride est très peu utilisée de nos jours, mais demeure une alternative aux propulsions conventionnelles. Dans le cas des plus grandes entreprises spatiales telles que la NASA, l’ESA et SpaceX, où la complexité et les coûts de production représentent moins un problème, la propulsion liquide est la meilleure alternative pour de meilleures performances. A l’inverse, dans l’astromodélisme, les moteurs disponibles publiquement dans le commerce sont toujours à propulsion solide. Dans ce cas-ci, les moteurs solides sont les plus simples et offrent des performances fables et bien suffisantes et fiables à la propulsion de petites fusées. Les moteurs hybrides sont donc un juste milieu très intéressant en termes de complexité et de performances.

7 LESTRADE, Jean-Yves. Modélisation de la régression des combustibles liquéfiables dans un moteur hybride [en ligne]. [S. l.] : [s. n.], [s. d.]. Disponible à l’adresse : https://depozit.isae.fr/theses/2012/2012_Lestrade_Jean-Yves.pdf. LESTRADE, Jean-Yves. Modélisation de la régression des combustibles liquéfiables dans un moteur hybride [en ligne]. [S. l.] : [s. n.], [s. d.]. Disponible à l’adresse : https://depozit.isae.fr/theses/2012/2012_Lestrade_Jean-Yves.pdf.

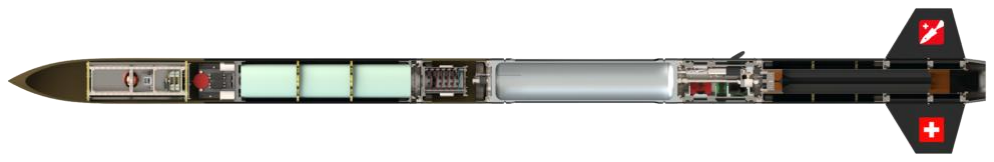
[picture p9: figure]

2024 | 14 | Gymnase de Morges

L’EPFL Rocket Team, que nous avons eu la chance de rencontrer, a construit dans le cadre de la compétition « Spaceport America Cup » les fusées « Bella Lui I » et « Bella Lui II », utilisant leur moteur hybride « Pegasus 10K »
8

. Ce dernier utilisant de l’ABS et du protoxyde d’azote comme ergols a produit 30 KN lors des tests. Nous ferons référence aux choix faits par l’EPFL Rocket Team lors de notre développement et comparerons nos résultats aux leurs, bien que l’échelle de production soit bien différente.

# 3.Méthodologie

Nous avons débuté ce TM avec une stratégie semblable à la firme de SpaceX⁹

. Elle se divise en
trois thèmes principaux :
1. Le Développement Itératif. En divisant le projet en petites parties menant chacune à de petites améliorations, il devient possible d’itérer plus rapidement. Ceci nous mène à une progression plus linéaire, moins échelonnée ainsi qu’un retour d’expérience plus fréquent permettant d’orienter le projet et les innovations régulièrement en évitant de longs mois de travail qui se termineraient sans résultats.
2. Se baser principalement sur les Tests en conditions réelles plutôt que sur des simulations implique des mises à l’épreuve régulières de notre moteur. Les données de ces tests sont précieuses et nous permettront d’identifier certains problèmes que les simulations n’auraient pu prédire. Parmi les tests, il y aura des échecs, mais il faut les voir comme des opportunités pour en apprendre plus sur une certaine variable, de bon vecteur pour le développement et les marqueurs de certaines limites matérielles.
3. « Best part is no part » (La meilleure pièce est celle qui n'existe pas). Notre but est de produire un moteur et un système qui soient le plus simple possible en y incorporant le moins de pièces différentes possibles, uniquement celles qui sont nécessaires. Moins il y a de matériaux différents et de pièces à acheter, plus nous pouvons nous en procurer de meilleure qualité. De plus, moins il y a de pièces, moins il y en a qui risquent de ne pas fonctionner ou de poser problème. Lors d’un échec, les pièces étant en nombre réduit, il devient plus simple de déterminer la faille du système et de la corriger.

8 Bella Lui II. Dans : EPFL Rocket Team [en ligne]. [s. d.]. [Consulté le 15 juillet 2024]. Disponible à l’adresse : https://epflrocketteam.ch/our-projects/bella-lui-2/. Bella Lui II. Dans : EPFL Rocket Team [en ligne]. [s. d.]. [Consulté le 15 juillet 2024]. Disponible à l’adresse : https://epflrocketteam.ch/our-projects/bella-lui-2/.
9 SpaceX est une entreprise fondée en 2002 par Elon Musk, active dans le domaine spatial et notamment en charge des projets de fusées Falcon9 et Starship.

Figure 7 : Coupe de la fusée Bella Lui II de l'EPFL rocket team - https://epflrocketteam.ch/fr/projets/bella-lui-2/.

2024 | 15 | Gymnase de Morges

Lors de la construction de la version initiale du moteur, nous nous sommes rendu compte que nous ne pourrions pas appliquer le développement itératif sur certaines parties du moteur. Bien que nous ayons conçu l’ensemble pour qu’il soit modulaire au maximum, il reste néanmoins des pièces qui sont longues et difficiles à modifier, par exemple la tuyère qui demande à être tournée sur un tour à métaux, qu’une fixation lui soit faite sur mesure et qu’une soudure spéciale soit appliquée. Tout ceci nécessitant plusieurs heures sur plusieurs jours, nous ne pouvons pas la changer à chaque test. Cependant, cette stratégie itérative fut appliquée pour le banc de test et l’électronique, profitant de leur facilité de conception et de construction.

# 3.1 Indexation des versions du moteur

Dans l’objectif de référencer nos versions et leur test et d’en posséder une chronologie claire et précise, nous avons élaboré un système d’appellation de toutes les versions du moteur. Ce dernier, utilisé tout au long du travail, nous a permis de mieux organiser les changements séparant deux versions et de s’y référer entre autres dans ce document. Au début nous ne savions pas le nombre de versions que nous élaborerions et encore moins l’étendue des changements que nous y apporterions. Nous avons donc défini que chaque version du moteur serait dotée d’un index du type :

VX-Y-Z

Où X,Y et Z sont des entiers évoluant dans l’ordre croissant (1, 2 puis 3, etc.) et V symbolise le terme « version ».
X) Le premier numéro représente le numéro de version principale. Il fut incrémenté uniquement lors de changements majeurs du moteur. De par le fait que nous ne connaissions pas l’ampleur du travail à son début, le seuil de changement considéré comme « majeur » fut déterminé au cours de ce dernier. Voyant que le moteur, performant dès le début, n’allait que peu changer, nous avons considéré entre autres comme changement majeur de version, le changement de la tuyère et l’agrandissement de l’orifice de l’injecteur.
Y) Ce deuxième numéro représente la sous-versions du moteur, incrémenté lors de chaque changement mineur, tel qu’une modification du bloc de carburant utilisé.
Z) Finalement, le dernier numéro correspond à l’index du test d’une même version. Par exemple le troisième test de la version du moteur V1-2 serait appelé V1-2-3.
Nous avons bien évidemment indexé la version initiale du moteur comme V1-1 et son premier test comme V1-1-1. Cette appellation fut notamment utilisée dans l’appellation des fichiers de données récoltés lors des tests et ceux résultant de leur interprétation. L’intégralité des versions et des tests ordonnées par ce même système d’indexation est disponible en annexe D.

2024 | 16 | Gymnase de Morges

# 4. Technologies utilisées

Afin de procéder à l’élaboration de ce projet interdisciplinaire, nous serons amenés à utiliser différentes techniques, outils et technologies afin d’assurer chacune des étapes dont les principales sont listées ci-dessous ;

## Logiciels

1. Afin de concevoir le moteur et son banc de test, nous avons utilisé le logiciel Fusion 360¹⁰ de la firme Autodesk. Ce logiciel est l’un des plus aboutis en termes de modélisation 3D. Il permet de modéliser des objets techniques en 3 dimensions, de tester des simulations de mouvements entre différents objets, ainsi que de tester la solidité des structures en simulant des contraintes. Dans le cadre de notre travail, nous l’utiliserons principalement afin de modéliser le banc de test, le moteur pour les rendus 3D, et les différentes pièces que nous imprimerons en 3D.
2. Pour les rendus de notre conception, nous avons utilisés le logiciel Blender¹¹

. Ce logiciel
gratuit étant open source bénéficie d’une large communauté et est simple d’utilisation. Il permet de créer des environnements virtuels en 3 dimensions, d’y ajouter des objets avec leurs textures, des lumières, et de créer des rendus 3D de ces environnements avec une gestion de la lumière et des ombres très réalistes. Une fonction similaire est directement intégrée à fusion 360 mais elle est moins pratique, moins documentée et n’offre pas la même qualité de finition.
3. Visual Studio Code¹² est un éditeur de texte permettant de rédiger du code dans un nombre important de langages, dont le Python que nous avons utilisé pour Rocket CEA et l’interprétation des données.
4. CEARUN¹³ (Chemical Equilibrium with Applications), ce programme de la Nasa disponible en ligne ou sous la forme d’une librairie Python dénommée Rocket CEA¹⁴. Cet outil permet de modéliser la combustion ayant lieu dans notre moteur.
10 Autodesk Fusion | 3D CAD, CAM, CAE, & PCB Cloud-Based Software | Autodesk. Dans : Autodesk
[en ligne]. [s. d.]. [Consulté le 4 juillet 2024]. Disponible à l’adresse : https://www.autodesk.com/ca-
fr/products/fusion-360/overview. Autodesk Fusion | 3D CAD, CAM, CAE, & PCB Cloud-Based Software |
Autodesk. Dans : Autodesk [en ligne]. [s. d.]. [Consulté le 4 juillet 2024]. Disponible à l’adresse : https://www.autodesk.com/ca-fr/products/fusion-360/overview.
11 FOUNDATION, Blender. blender.org - Home of the Blender project - Free and Open 3D Creation Software. Dans : blender [en ligne]. [s. d.]. [Consulté le 4 juillet 2024]. Disponible à l’adresse : https://www.blender.org/. FOUNDATION, Blender. blender.org - Home of the Blender project - Free and Open 3D Creation Software. Dans : blender [en ligne]. [s. d.]. [Consulté le 4 juillet 2024]. Disponible à l’adresse : https://www.blender.org/.
12 MICROSOFT. Visual Studio Code [en ligne]. [s. d.]. [Consulté le 5 juillet 2024]. Disponible à l’adresse : https://code.visualstudio.com/. MICROSOFT. Visual Studio Code [en ligne]. [s. d.].
[Consulté le 5 juillet 2024]. Disponible à l’adresse : https://code.visualstudio.com/.
13 CEARUN rev4. Dans : NASA [en ligne]. [s. d.]. [Consulté le 15 juin 2024]. Disponible à l’adresse : https://cearun.grc.nasa.gov/. CEARUN rev4. Dans : NASA [en ligne]. [s. d.]. [Consulté le 15 juin 2024]. Disponible à l’adresse : https://cearun.grc.nasa.gov/.
14 RocketCEA Wraps The NASA FORTRAN CEA Code And Provides Some Useful Tools — RocketCEA v1.2.0 documentation [en ligne]. [s. d.]. [Consulté le 5 juillet 2024]. Disponible à l’adresse : https://rocketcea.readthedocs.io/en/latest/. RocketCEA Wraps The NASA FORTRAN CEA Code And Provides Some Useful Tools — RocketCEA v1.2.0 documentation [en ligne]. [s. d.].
[Consulté le 5 juillet 2024]. Disponible à l’adresse : https://rocketcea.readthedocs.io/en/latest/.

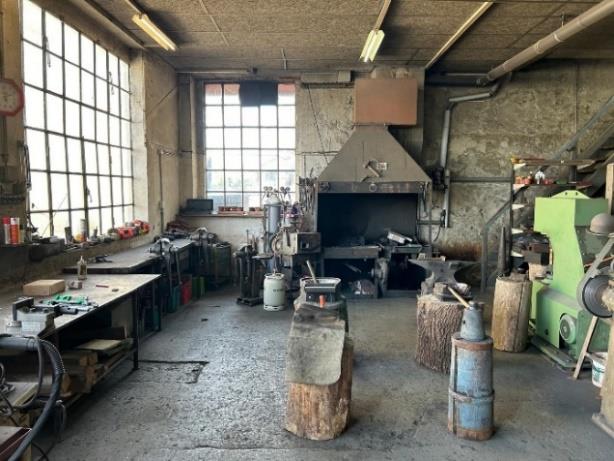
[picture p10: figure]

2024 | 17 | Gymnase de Morges

Ce logiciel permet aussi d’analyser une partie de ses performances. Voici quelques-unes de ses fonctionnalités :

a. Déterminer la composition des produits de combustion à l'équilibre.
b. Calculer l’impulsion spécifique, la température de la flamme, la pression dans la chambre de combustion et la vitesse d’éjection.
c. Effectuer des simulations sur une plage de valeur permettant de sélectionner certains paramètres pour un test.
5. Les logiciels Word et Excel de la suite Microsoft 365 nous serviront respectivement pour la rédaction du TM et l’étude des données.

## Outils

1. Pour l’ordinateur de bord du moteur qui a servi à la récolte de données, nous nous sommes basés sur des cartes Arduino¹⁵ que nous avons programmées en langage du même nom. Nous avons utilisé l’Arduino IDE pour téléverser le code sur la carte. C’est un éditeur de code acceptant l’Arduino et simplifiant le lien entre l’ordinateur et la carte électronique.

## Techniques

1. Nous avons à disposition un atelier de serrurerie à Ballens contenant un tour à métaux, de quoi souder, forger, braser, percer et découper que nous utiliserons afin d’usiner différentes pièces.
2. Les technologies liées à l’impression 3D
FDM | (Fused | Deposition | Modeling)
consistent en l’extrusion d’un matériau couche par couche pour créer un objet en 3D. Un filament principalement composé de thermoplastique est fondu dans une buse et
déposé selon un chemin prédéterminé sur
un plateau chauffé à sa température de
transition vitreuse pour la première couche, puis sur la couche précédente.
Pour passer d’un modèle en 3D à un fichier d’instructions compréhensible par l’imprimante appelé « fichier G-Code », nous utiliserons Orca slicer¹⁶. Ce logiciel est open source et nous permet d’envoyer directement les fichiers à nos imprimantes sans utiliser une clef USB ou une carte micro SD.

15 Arduino - Home [en ligne]. [s. d.]. [Consulté le 4 juillet 2024]. Disponible à l’adresse : https://www.arduino.cc/. Arduino - Home [en ligne]. [s. d.]. [Consulté le 4 juillet 2024]. Disponible à l’adresse : https://www.arduino.cc/.
16 SOFTFEVER. OrcaSlicer [en ligne]. [s. d.]. [Consulté le 4 juillet 2024]. Disponible à l’adresse : https://github.com/SoftFever/OrcaSlicer. SOFTFEVER. OrcaSlicer [en ligne]. [s. d.].
[Consulté le 4 juillet 2024]. Disponible à l’adresse : https://github.com/SoftFever/OrcaSlicer.

Figure 8 : Atelier de serrurerie à Ballens - photo personnelle.

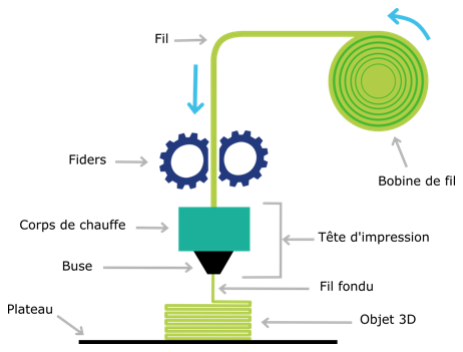
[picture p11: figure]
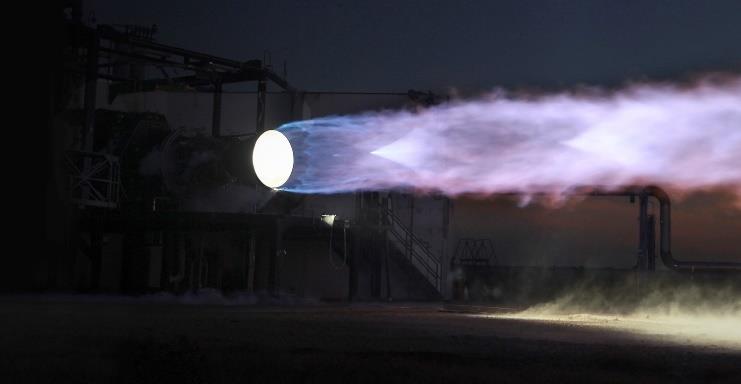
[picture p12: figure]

2024 | 18 | Gymnase de Morges

Nous pouvons imprimer avec quatre types de filaments :

- Le PLA fait à base d'amidon de maïs
est de loin le plus simple à imprimer,
il est rigide mais apporte une
certaine faiblesse sur sa résistance à de fortes charges.
- Le PETG résistant aux chocs mais tendant à se déformer reste néanmoins simple à imprimer.
- L’ABS est un matériau rigide et résistant cependant il nécessite d’être imprimé sur un plateau chauffé à très haute température et est victime du « warping » et à la délamination (séparation entre les
couches). Ce filament servira de
carburant pour notre moteur.
- L’ASA est un dérivé de l’ABS, il présente une bonne résistance aux chocs et aux UV mais est moins rigide. Il pose les mêmes problèmes que l’ABS lors de l’impression. Ce filament servira aussi de carburant pour notre moteur.
Il est possible d’imprimer des versions de ces filaments contenant des additifs comme du PLA-CF qui contient des fibres de carbone pour améliorer sa rigidité et sa résistance à de grandes charges, tout en conservant sa simplicité d’impression. Lors de l’impression de ces filaments, l’imprimante doit être équipée d’une buse en acier trempé car ces filaments sont abrasifs et une buse traditionnelle en laiton risquera de diminuer la précision de l’extrusion voire même de ruiner l’impression.
3. Grâce à l’impression 3D, nous avons eu l’occasion de fabriquer des moules afin d’y couler des matériaux tels que du ciment.

# 5.Banc de test du moteur

## Version initiale

Lors du développement d’une technologie,
les tests fréquents sont un excellent moyen d’analyser l’avancée du projet. Cependant, dans le cas d’un moteur-fusée, les premiers tests du moteur dans des vols en conditions réelles sont premièrement, rarement concluant, et deuxièmement extrêmement coûteux. Ainsi, afin de tester et certifier les performances d’un moteur-fusée avant de lui faire quitter la surface de la terre, les moteurs sont testés dans ce qu’on appelle des tests statiques.

Figure 10 : Test statique d’un moteur Raptor de SpaceX, 2019 -https://www.teslarati.com/spacex-elon-musk-starship-raptor-test-stand-upgrades/.

Figure 9 : Schéma de l'impression 3D FDM -https://www.linkedin.com/pulse/limpression-3d-dans-lindustrie-micro-erosion/.

2024 | 19 | Gymnase de Morges

Ce genre de tests a pour but de faire performer le moteur solidement fixé au sol, en mesurant ses performances, afin d’estimer ses résultats potentiels en conditions réelles. Parmi ces données, on y mesure principalement la poussée, soit la force qu’exerce le moteur sur la structure le retenant. Cette force en newtons permet d’en déduire la charge que le moteur pourrait faire théoriquement décoller. En couplant cette valeur à d’autres données, telle la durée de combustion du moteur, cela permet d’estimer les caractéristiques théoriques lors d’un vol (vitesse, altitude, etc.). Ces tests, faciles à mettre en place, présentent aussi quelques inconvénients. Premièrement, les tests statiques ne prennent pas en compte la diminution de la pression atmosphérique avec l’altitude. En effet, les tuyères du type de Laval, étant les plus utilisées en aérospatiale, sont optimisées pour fonctionner avec une pression ambiante bien spécifique. Dans le cas où cette dernière vient à s’éloigner de celle pour laquelle la tuyère a été conçue, il s’y produit une perte d’efficacité et une diminution de la poussée du moteur (cf. équation 13). En raison de ce phénomène, les tuyères sont généralement optimisées pour le milieu spécifique dans lequel il est le plus important d’obtenir un maximum de poussée. Deuxièmement, ils modifient l’orientation du moteur par rapport aux vols réels (en exerçant les tests à l’horizontale par exemple). Ce changement peut avoir pour effet, notamment pour les moteurs hybrides, de faire couler le combustible liquéfié vers le côté du moteur et non dans le sens des gaz. Nous avons également observé que le bloc de combustible avait tendance à s’affaisser sur lui-même durant les tests. Bien que son influence sur les performances du moteur soit probablement négligeable comparée à la quantité de poussée produite, utiliser le moteur de manière verticale devrait augmenter très légèrement ses performances. Dans le cas où nous aurions voulu effectuer ces deux changements afin de se rapprocher des conditions réelles d’un moteur-fusée, nous aurions dû construire un banc de test vertical différent et effectuer les tests dans une chambre étanche en variant la pression à l’intérieur. Par souci de faisabilité, nous avons pris la décision de négliger les effets de ces deux écarts à la réalité. Les moteurs-fusées étant extrêmement puissants, ces tests nécessitent une structure complexe et suffisamment résistante aux contraintes imposées par le moteur. Ce dispositif, appelé banc de test, doit aussi assurer la collecte des données pertinentes résultant des performances du moteur.
Dans le cadre de notre travail, nous n’avons pas procédé à des tests en conditions de vol mais uniquement à des tests statiques. Nous avons alors très tôt commencé la conception et la construction d’un banc de test répondant à nos attentes.
Le banc de test devait :
- Permettre de récolter suffisamment de données pertinentes à l’analyse des performances du moteur.
- Permettre au moteur un mouvement linéaire à faibles frottements, afin de déformer le capteur de poussée.
- Être composé de pièces facilement disponibles.
- Être facilement assemblable et démontable.
- Permettre d’être solidement fixé au sol.
- Résister aux températures élevées à la surface du moteur.
Le capteur de poussée du moteur fonctionne de façon à mesurer sa déformation structurelle, due à la force qu’applique le moteur sur sa surface. Il est donc nécessaire de laisser au moteur la possibilité de se déplacer linéairement et de déformer le capteur en butée.

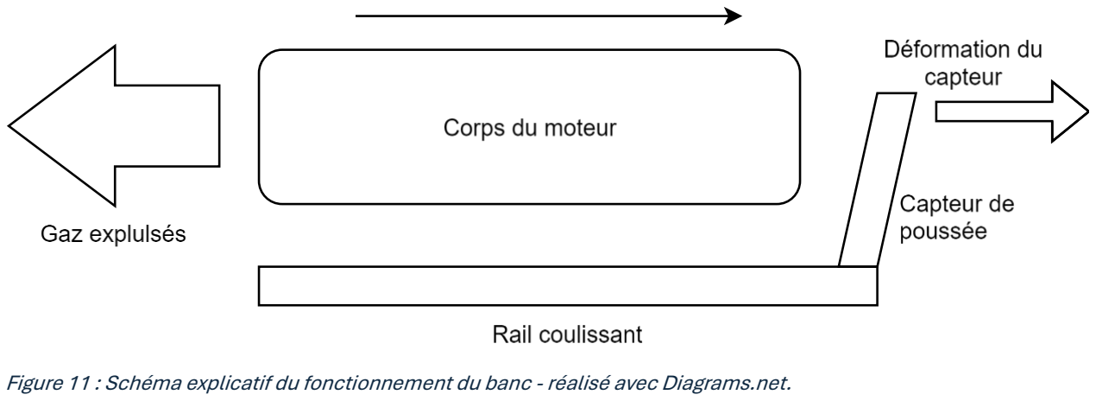
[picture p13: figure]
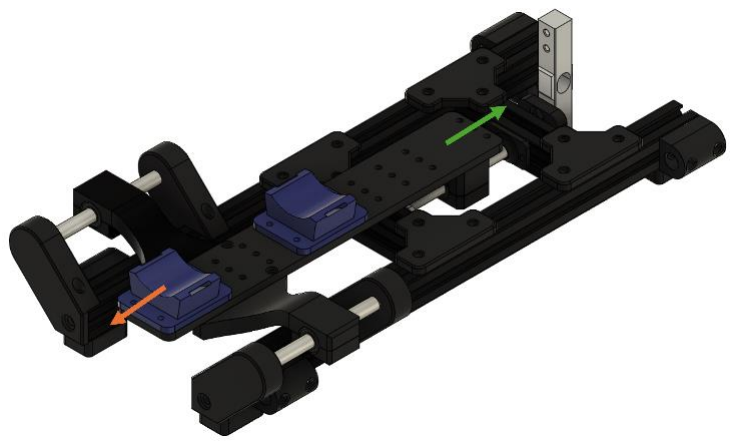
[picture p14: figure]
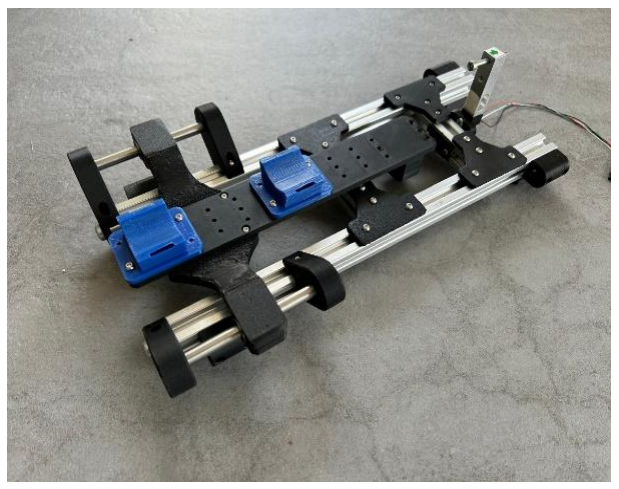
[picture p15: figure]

2024 | 20 | Gymnase de Morges

Dans le cas où le moteur serait fixé en tout point, l’énergie cinétique du moteur serait uniquement dissipée dans la structure l’empêchant de bouger, et aucune mesure de la poussée ne pourrait être récoltée.
Afin de garantir un mouvement linéaire,
stable et sans frottements, nous avons
utilisé trois tiges d’aluminium avec six
roulements | linéaires. | La | structure
principale du banc de test est constituée de deux profilés en aluminium parallèles, tenus ensemble par deux autres profilés. Ce type de structure composé de profilés en aluminium permet notamment d’être assemblé et modifié facilement, soit en taraudant leurs extrémités ou en utilisant de petits écrous en forme de T appelé « T-Nuts », se bloquant dans les rainures des profilés.
Ce type de structure est très utilisé dans ce
domaine et dans les installations
expérimentales, car il permet un prototypage rapide. Afin de maintenir la structure, nous avons utilisé différentes pièces imprimées en 3D. Le banc de test possède un plateau imprimé en 3D disposant d’une grille d’emplacement pour vis et écrous, nous permettant de fixer n’importe quel support par-dessus et d’accueillir tout type de moteur
Le banc de test a été entièrement modélisé dans le logiciel Fusion 360 avant la commande et l’impression en 3D des différentes pièces. Nous avons ensuite pu l’assembler sans difficultés et développer le système d’acquisition de données.

Figure 11 : Schéma explicatif du fonctionnement du banc - réalisé avec Diagrams.net.

Figure 12 : Rendu 3D du banc de test modélisé - rendu réalisé avec Fusion 360.
Le moteur se fixe sur les deux supports (en bleu) et déplace le chariot coulissant vers la droite (flèche verte). Les gaz sont éjectés à l’opposé (vert orange).

Figure 13 : Le banc de test une fois assemblé - photo personnelle.

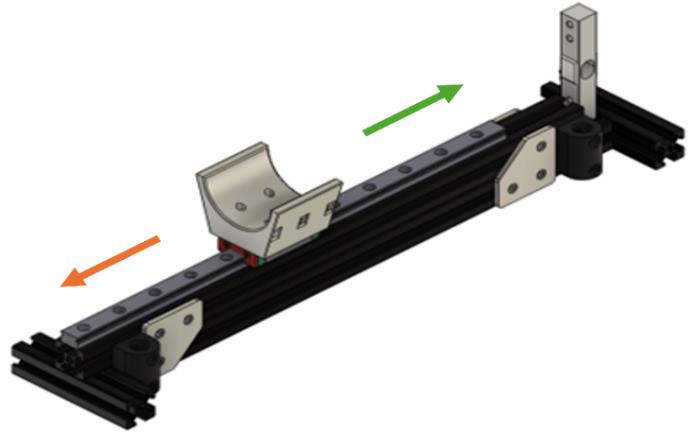
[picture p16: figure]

2024 | 21 | Gymnase de Morges

## Version ultérieure

Lors de l’élaboration de la version 3 du moteur, plusieurs défauts remarquables du banc de test utilisé jusqu’ici là nous ont poussés à concevoir et construire un banc différent et plus efficace. Nous avions remarqué les défauts suivants lors des premiers tests du moteur :
- Le banc comportait de nombreuses pièces plastiques qui étaient susceptibles de fondre au contact du moteur extrêmement chaud.
- Le banc étant fixé au ras du sol, l’herbe sur notre zone de tir empêchait le mouvement du chariot et faussait les résultats.
- Le poids du moteur déformait la plaque principale en charge de son maintien freinant le mouvement du banc et, à nouveau, faussant les données récoltées.
En effet, des calculs structuraux auraient pu être effectués avant la construction de la première version du banc afin de garantir la résistance lors des tests. N’ayant cependant pas à notre disposition le matériel ainsi que les compétences requises pour faire de telles simulations, nous avons préféré construire une première version du banc dans le but de l’itérer dans le cas où elle ne saurait être suffisamment résistante.
Pour corriger ces défauts tout en conservant
les mêmes fonctionnalités, nous avons opté
pour un rail linéaire MGH-12. Ce rail, plus robuste, permet le coulissement du moteur, fixé à un chariot. La base du rail est fixée sur les mêmes profilés en aluminium 2020 superposés afin d’éloigner le banc du sol. D’autres profilés, fixés avec des supports imprimés en 3D et ancrés au sol par des sardines, assurent la stabilité de l’ensemble. Enfin, un capteur de force, placé à l’extrémité
du moteur, mesure la poussée comme le banc
précèdent.

# 5.1 Système d’acquisition de données

Lors des tests d’un moteur-fusée, les données récoltées sont cruciales afin d’analyser ses performances. Notre moteur ne faisant pas exception, nous avons principalement utilisé les méthodes suivantes afin de récolter le maximum de données obtenables. Notre source principale d’acquisition de données fut l’utilisation de capteurs électroniques couplés à un microcontrôleur, ainsi que des caméras et des microphones. Nous détaillons ces méthodes plus précisément ci-dessous :

## Système principal d’acquisition de données

### - Microcontrôleur utilisé

Afin de récolter et mémoriser les données numériques des différents capteurs, nous avons dû choisir un microcontrôleur programmable adapté à nos besoins. Après en avoir comparé les

Figure 14 : Rendu 3D du banc de test V2 modélisé - photo personnelle.
Les gaz sont éjectés à gauche (flèche orange) et le moteur se déplace vers l’opposé (flèche verte).

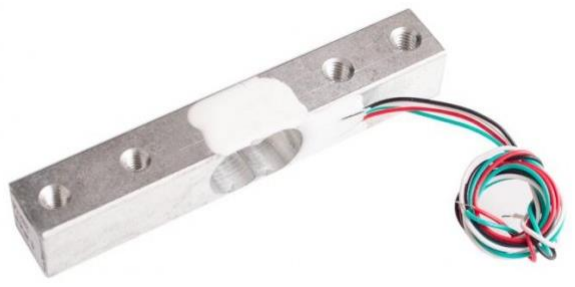
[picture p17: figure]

2024 | 22 | Gymnase de Morges

alternatives, nous avons choisi l’Arduino Nano¹⁷ et ceci pour les raisons suivantes. Des clones fidèles de ce microcontrôleur populaire et grandement documenté sont facilement disponibles en ligne à moins de CHF 5.-. Il possède un grand nombre de pins analogiques et digitaux et dispose d’une puissance de calcul suffisante pour notre utilisation. Connecté à un ordinateur, il peut être très facilement programmé via le logiciel de la firme Arduino Ide et son langage associé. Ce choix nous semblait évident et assurait une programmation facilitée, ainsi que la fiabilité lors de son utilisation.

### - Mesure de la poussée

La mesure de la poussée du moteur est
certainement la donnée la plus importante à récolter. En effet, la force de poussée induite par le moteur (en newtons) est l’indicateur le plus marqué des performances du moteur. Afin de récolter en toute fiabilité cette mesure, nous avons utilisé un capteur électronique que nous avons calibré avant chaque test. Ce capteur, appelé « Load Cell », convertit une force en variation de tension électrique, en mesurant la déformation
structurelle imposée par la poussée sur le capteur.
Plus précisément, les contraintes structurelles
imposées déforment un circuit imprimé très fin, appelé jauge de déformation, en allongeant ou raccourcissant la longueur d’un conducteur, modifiant ainsi sa résistance électrique. Cette variation étant infime, un montage en pont de Wheatstone avec 4 jauges de déformation est parfois utilisé pour l’amplifier. Cette variation modifie la tension entre les différents fils colorés, pouvant alors être mesurée et interprétée.
Afin de permettre à l’Arduino Nano de mesurer ces variations, nous avons également utilisé un module amplificateur HX711

### - Calibration de la « Load Cell »

On calibre une « Load Cell » en appliquant des forces ou des masses connues pour mesurer la réponse en tension ou en courant. Lorsque l’on calibre la cellule de charge seule, on peut lui appliquer des forces connues directement sur le capteur pour en déterminer la réponse, la linéarité de celle-ci et la précision de la mesure sans aucune interférence du banc de test et des autres composants. Nous avons utilisé cette manière de calibrer pour les trois premières journées de test.Cependant cette méthode ne permet pas de tenir compte des autres éléments qui peuvent modifier la réponse de celle-ci dans des conditions réelles, tels que les vibrations, les frottements, et l’imperfection de l’alignement. Ces facteurs ne sont pas simulables à notre échelle sans calibration de la cellule avec le système complet. Lorsque l’on calibre ce composant avec le reste du système, on peut tenir compte des interaction suivantes :
- Les forces parasites : les forces qui ne proviennent pas directement de la poussée du moteur mais de vibrations, de flexions dans la structure du banc, ou de mouvements non voulus.

17 Arduino Nano. Dans : Arduino Official Store [en ligne]. [s. d.]. [Consulté le 14 août 2024]. Disponible à l’adresse : https://store.arduino.cc/products/arduino-nano.

Figure 15 : Capteur de poussée utilisé -https://www.tinytronics.nl/en/sensors/. Une extrémité est solidement attachée et une force est appliquée à l'autre extrémité. La variation de tension électrique peut être mesurée entre les différents fils colorés.

2024 | 23 | Gymnase de Morges
- Les contraintes structurelles : le montage de la « Load Cell » peut subir des pressions supplémentaires ou des déformations qui ne sont pas présentes lors de la calibration isolée.
- Les pertes de friction : notre banc étant équipé d’un rail linéaire légèrement résistant, il a dissipé une partie de la poussée par friction. Nous aurions pu en effet mesurer cette résistance séparément et en tenir compte lors des calculs, mais nous n’étions pas en mesure d’obtenir des résultats fiables et répétables dans le temps.
Pour minimiser l’impact de ces facteurs, nous avons calibré la « Load Cell » en testant des forces connues sur le moteur monté sur le rail lors des tests de la V3, mais nous ne sommes pas entièrement certains de ce choix.

### - Mesure des températures

Afin de quantifier l’énergie thermique produite par la combustion, nous avons utilisé plusieurs capteurs de température placés à différents endroits du moteur. Cela nous a également permis de comparer ces températures à celles de fusion des matériaux utilisés et d’en déterminer l’écart. Nous avons utilisé pour chacun des tests, trois thermistances, ou capteurs de température, que nous avons connectées au microcontrôleur dans un montage dit en « Pull-Up ». Un capteur de température consiste simplement en un composé ohmique possédant une résistance interne variable avec la température, dit thermistance, et relié par deux fils. Les caractéristiques d’une thermistance sont définies principalement par sa résistance électrique à température ambiante, ainsi que par son type pouvant être dit NTC - dans le cas où sa résistance diminue lorsque la température augmente - ou PTC pour l’inverse.
Pour permettre au microcontrôleur d’interpréter la température, il devra en mesurer une tension via un pin analogique. Afin de permettre une mesure stable, nous devions utiliser un montage en Pull-Up. Cela consiste à placer en série la thermistance et un composé ohmique de résistance interne connue, entre le GND et le 5V du microcontrôleur. Nous pouvons ensuite connecter le pin analogique de l’Arduino entre le composé ohmique de résistance connue et la thermistance, puis mesurer une tension permettant ensuite d’en déduire la température.
Nous avons choisi pour ce travail d’utiliser des thermistances de résistance de 100k Ω et de type NTC. Après avoir renseigné ces informations dans le code, nous étions capables de mesurer des températures fiables avec une précision de ± 1°C.

### - Capteur de pression

Une autre donnée représentative des performances du moteur est la pression interne dans la chambre de combustion. Cette valeur (en Pa ou bars) peut être utilisée dans de nombreuses équations liées aux performances des moteurs-fusées et permet également d’évaluer l’écart entre la pression mesurée et le maximum imposé par la structure du moteur.
Très semblable à la Load Cell utilisée pour mesurer la poussée du moteur, ce capteur utilise également une jauge de déformation pour convertir la force due à la pression de l’air sur le capteur en variation de tension électrique.
Nous avons alors sélectionné, entre la V1 et la V2, un capteur pouvant supporter jusqu’à 35 bars, supérieur aux 15 bars que peut délivrer notre détendeur au maximum, nous offrant ainsi une marge de sécurité amplement suffisante. Le capteur a été inséré dans un raccord de 1/8 de pouce

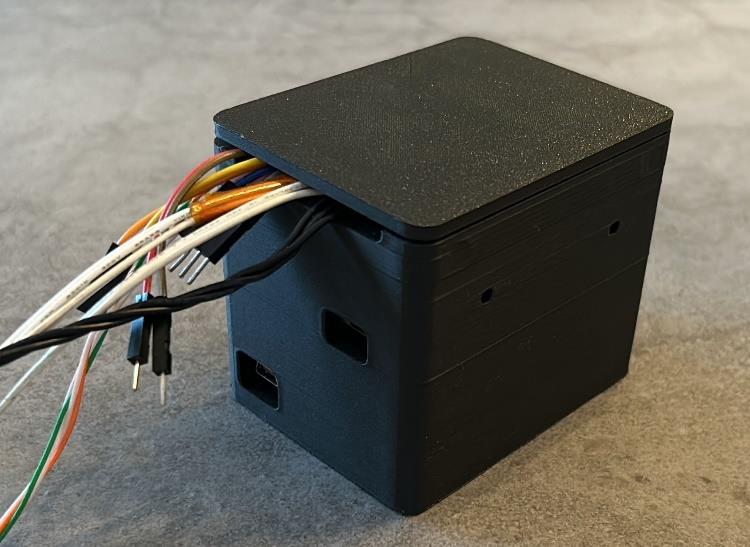
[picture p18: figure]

2024 | 24 | Gymnase de Morges

en laiton que nous avions précédemment brasé au moteur. Nous n’avons cependant utilisé ce capteur qu’à partir de la version numéro V2.

### - Stockage des données

Dans l’objectif de conserver le plus efficacement possible l’intégralité des données acquises durant les tests, nous avons choisi d’utiliser un module lecteur de carte SD, communiquant avec le microcontrôleur via une liaison SPI (Serial Peripheral Interface). Les résultats de chaque test ont été stockés dans des fichiers séparés au format .txt (fichier texte) sous la forme d’un tableau csv (Comma-Separated Values). Ces valeurs ont par la suite pu être aisément importées dans le logiciel Excel afin de les traiter.

### Assemblage et programmation

Nous avons effectué les diverses
connections entre les différents composants électroniques à l’aide de câbles à connecteurs « Dupont » et de
PCB, | destinés | aux | montages
électroniques | expérimentaux. | Les
composants ont été soudés aux PCB par des brasures à l’étain au moyen de postes à souder. La programmation de l’Arduino Nano a été effectuée via le logiciel de la firme Arduino Ide et son langage de programmation associé (dérivé du C++). Ce langage peut être couplé à de multiples librairies
développées | par | la | grande
communauté du domaine, rendant la
programmation simple et intuitive. Une fois connecté via une connexion USB avec un ordinateur, il est possible de compiler le code déjà écrit et de le transverser via la connexion serial sur l’Arduino.
En conservant cette communication, il est possible de faire communiquer dans les deux sens le microcontrôleur et l’ordinateur via un terminal appelé « Serial Monitor ». Afin d’interpréter les données brutes des différents capteurs, nous avons utilisé plusieurs librairies de la communauté¹⁸,19,20,21 ainsi que leurs documentations associées. Le déroulement du code peut ainsi être résumé comme suit :
Après avoir initialisé chaque composant, l’utilisateur renseigne, via le Serial Monitor, l’indicatif du test, du type V1-1-1, puis débute la boucle principale récupérant et stockant les données. Dans cette boucle, les données des différents capteurs sont premièrement récupérées et stockées

18 BADEA, Laurentiu. StepperDriver [en ligne]. [s. d.]. [Consulté le 30 juillet 2024]. Disponible à l’adresse : https://github.com/laurb9/StepperDriver/tree/master.
19 ARDUINO LIBRARIES. SD Library for Arduino [en ligne]. [s. d.]. [Consulté le 18 mars 2024]. Disponible à l’adresse : https://github.com/arduino-libraries/SD.
20 ALEX, mr. NTC_Thermistor [en ligne]. 18 mars 2024. [Consulté le 18 mars 2024]. Disponible à l’adresse : https://github.com/suoapvs/NTC_Thermistor.
21 OLKAL. HX711_ADC [en ligne]. 29 mars 2024. [Consulté le 29 mars 2024]. Disponible à l’adresse : https://github.com/olkal/HX711_ADC.

Figure 16 : Photographie de l'ordinateur d'acquisition de données lors des derniers tests dans une boite imprimée en 3D - photo personnelle.

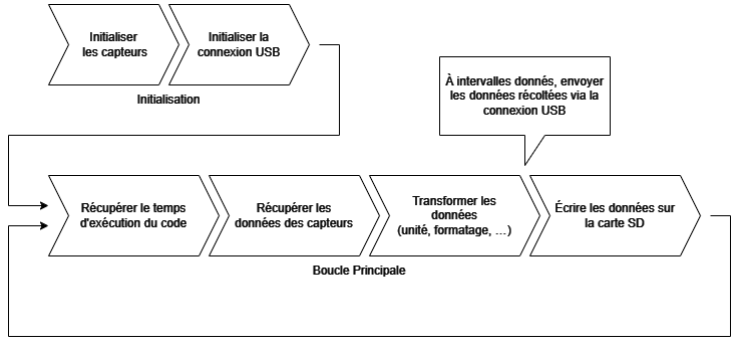
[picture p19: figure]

2024 | 25 | Gymnase de Morges

temporairement, puis écrites sur un fichier du même indicatif que le test (par exemple : V1-1-1.txt) sur la carte micro SD. A intervalles réguliers, une partie de ces données sont aussi envoyées via USB au Serial Monitor, afin d’être visualisées sur un ordinateur durant le test. Un délai peut également être placé en fin de boucle, dans le but de limiter la quantité de données enregistrées. Cependant, n’étant pas limités par la taille des fichiers textes, il nous a semblé préférable de stocker le maximum de données possibles pour une meilleure précision lors de leur analyse. L’entièreté du code utilisé lors du dernier test est disponible en annexe A et B.

Figure 17 : Schéma explicatif du programme utilisé par le microcontrôleur principal - réalisé avec Diagrams.net.

## Vidéos et enregistrements audios

Nous avons également filmé et enregistré l’audio de chacun des tests au moyen d’un ou plusieurs téléphones portables. Ces enregistrements nous ont ensuite permis d’en extraire visuellement d’autres données,telle la durée de la combustion, la puissance de la flamme ou encore l’intensité sonore durant le test. Pour certains tests, un masque de soudure a été placé devant l’un des objectifs, dans le but de masquer l’excédent de lumière des flammes et d’y percevoir les ondes de chocs, appelées « Shock Diamond » ou disques de Mach²². L’identification de ce phénomène devait nous permette d’estimer la vitesse des gaz éjectés relativement à la vitesse du son.

## Interprétation des données

Après chaque test, nous avons utilisé le logiciel Excel pour traiter les données stockées sous forme de fichier CSV par le système d’acquisition principal, d’en calculer d’autres données telles que l’impulsion totale, afin de les visualiser sous la forme de graphiques. Ces données ont été primordiales et nous ont permis, en les analysant, d’en déduire les améliorations des versions ultérieures.

22 Disque de Mach [en ligne]. [S. l.] : [s. n.], 28 décembre 2021. [Consulté le 14 août 2024]. Disponible à l’adresse : https://fr.wikipedia.org/w/index.php?title=Disque_de_Mach&oldid=189301994. Page Version ID: 189301994.

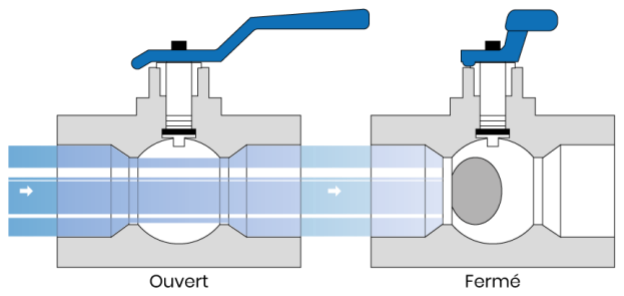
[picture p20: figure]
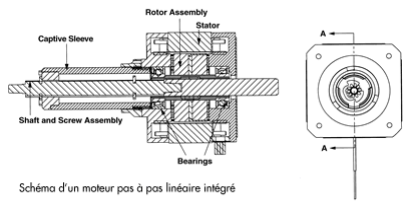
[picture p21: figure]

2024 | 26 | Gymnase de Morges

Par la suite, et afin de permettre une analyse plus rapide des données récoltées après chaque test, nous avons développé et utilisé un programme en Python capable, en indiquant quelques paramètres importants, de calculer les valeurs essentielles résumant le test (telles que la poussée moyenne, l’impulsion totale, etc.) et de les afficher automatiquement sous forme de graphiques. Ce programme extrêmement complet a également été couplé à RocketCEA afin d'intégrer automatiquement ses valeurs calculées aux résultats du test. L’intégralité du code utilisé est disponible en annexe C.

# 5.2 Motorisation de la vanne de l’injecteur

Pour des raisons de sécurité et afin de
contrôler la durée et l’intensité des
tests, un moyen de moduler la
combustion interne au moteur nous était nécessaire. Sachant que le carburant ne brûle pas de manière intense au contact de l’air, la solution la plus évidente a été de contrôler l’apport en oxygène du moteur. Dans le premier
test, nous avons utilisé la vanne
principale de la bonbonne d’oxygène
afin d’ouvrir et de fermer l’apport en oxygène et de contrôler la combustion. Cependant, cette solution limitait la distance de sécurité autour du moteur à la longueur du tuyau d’oxygène. Afin de remédier à cette problématique et afin de pouvoir contrôler électroniquement la durée des tests, nous avons conçu un système pour motoriser l’une des vannes de la tuyauterie responsable de l’apport en oxygène.
Lors d’une discussion avec l’EPFL
Rocket Team, nous avons saisi l’idée de
motoriser cet apport en actionnant une vanne à bille à l’aide d’un servomoteur
(type | de | moteur | électronique
facilement | programmable | et
contrôlable par des impulsions PWM). Ce système fut d’ailleurs utilisé par l’EPFL afin de moduler l’injection de protoxyde d’azote (N2O) dans leur
moteur hybride Pegasus 10K utilisé lors
du projet Bella Lui II. Leur système
comprenait un servomoteur de très haut couple lié à la poignée d’une vanne à bille par des pièces métalliques. N’ayant pas à notre disposition le matériel nécessaire à l’élaboration de ce système, nous avons essayé de concevoir une alternative imprimée en 3D, utilisant notamment des roues dentées afin de gagner en couple. Cependant malgré le rapport de démultiplication 1:2 des roues dentées utilisées, l’unique vanne à bille que nous possédions demeurait trop difficile à tourner. Comme deuxième solution, nous avons utilisé une autre vanne déjà présente dans la tuyauterie du moteur, cette fois-ci s’ouvrant sur une plage de mouvement de 6 tours, beaucoup plus facile à tourner. Quant au choix du moteur, utiliser le même servomoteur que précédemment aurait nécessité un autre montage de roues dentées afin de gagner en plage de mouvement. Cependant,

Figure 18 : Schéma de fonctionnement d'une vanne à bille -https://www.cgr-robinetterie.fr/fr/robinets-boisseau-spherique/.

Figure 19 : Schéma d'un moteur pas à pas -https://rotero.com/be-fr/moteurs-pas-a-pas-lineaires.

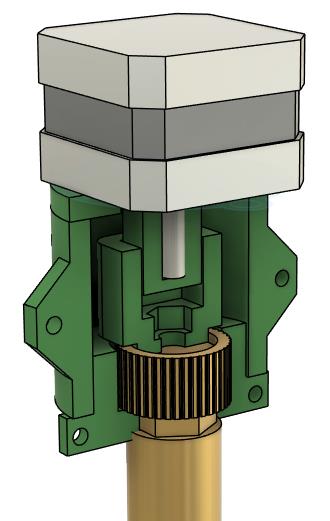
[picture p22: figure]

2024 | 27 | Gymnase de Morges

cela aurait également nécessité bien plus de couple au moteur. Nous avons alors décidé d’utiliser un autre type de moteur, souvent utilisé en impression 3D, appelé moteur pas-à-pas. Plus précisément, nous en avons utilisé un de type Nema-17, qui estle plus fréquemment employé.
Ce type de moteur utilise un shaft (axe central tournant sur lui-même) mis en rotation par deux bobines servant d’électro-aimant. Il n’est alors contraint par aucune limite de mouvement et possède suffisamment de force pour faire tourner la vanne. Nous avons ainsi conçu et modélisé un support imprimable en 3D afin de maintenir le moteur en position et de lier le shaft avec la vanne. L’une des principales problématiques lors de cette conception fut le fait que la vanne s’élevait au fur et à mesure de sa rotation. Nous ne pouvions alors pas fixer le moteur, sans quoi la vanne aurait été bloquée par son impossibilité à s’élever. Pour remédier à ce problème, nous avons modélisé le lien entre la vanne et le shaft en laissant coulisser linéairement un cube accroché au shaft dans une autre pièce percée d’un cube fixé à la vanne (voir figure 21). Le mouvement fut alors transmis entre les deux éléments tout en laissant à la vanne la possibilité de s’élever.
Afin de programmer le moteur, nous avons utilisé un deuxième microcontrôleur du même type que celui d’acquisition des données. Cette solution permet à un microcontrôleur de s’occuper uniquement de la collecte de données, tandis que l’autre gère indépendamment la rotation du moteur.
En plus de permettre une prise de données plus régulière et non interrompue, le dédoublement des microcontrôleurs assure qu’en cas de fermeture d’urgence de la vanne, le programme ne soit pas gêné par un disfonctionnement de l’autre Arduino Nano. Afin de gérer les électro-aimants à partir des impulsions transmises par le microcontrôleur, nous avons dû utiliser un « driver » entre les deux. Dans ce cas-ci, nous avons utilisé un driver populaire et bon marché du type A4988. La programmation du deuxième microcontrôleur s’est également faite via le logiciel Arduino Ide et son langage associé en utilisant une librairie populaire créée par la communauté²³

. Une fois
programmé, nous avons relié par un long fil électrique un interrupteur au microcontrôleur. Celui-ci nous a permis de démarrer à distance le test et de l’interrompre à tout moment en cas de besoin. Ce microcontrôleur indiquait également à celui responsable de la prise de données, l’état de la vanne – soit 0 ou 1 – afin qu’il l’enregistre avec le reste des données sur la carte SD. Un des pins de sortie (output pin) du microcontrôleur du moteur était relié à un pin d’entrée (input pin) de l’autre microcontrôleur, étant soit défini sur HIGH ou LOW selon l’état de l’interrupteur. Ceci nous a permis de retrouver plus facilement, parmi les grandes quantités de données récoltées, le début et la fin du test lors de l’analyse.

23 WASPINATOR. AccelStepper [en ligne]. 19 août 2024. [Consulté le 26 août 2024]. Disponible à l’adresse : https://github.com/waspinator/AccelStepper.

Figure 20 : Vue de coupe de la conception du support du moteur - rendu réalisé avec Fusion 360.
En jaune la vanne, en vert le support imprimé en 3D et au-dessus le moteur pas à pas.

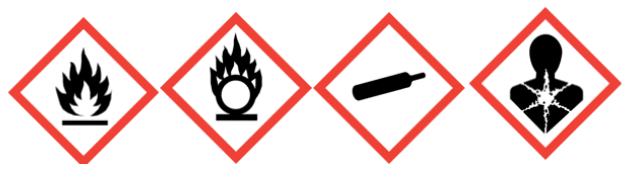
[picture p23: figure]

2024 | 28 | Gymnase de Morges

# 6.Sécurité et règlementations

# 6.1 Risques et précautions

La conception de moteurs-fusées comporte de nombreux risques et est donc strictement réglementée par l’Etat. En effet, ce travail nécessite la manipulation de gaz sous pression et de substances inflammables, comburantes et potentiellement dangereuses pour la santé. Nous avons également été amenés à manipuler des machines d’usinage métallique présentant certains risques. Afin de minimiser les risques lors de ce travail, nous avons appliqué les mesures de sécurité réalisables et suffisantes, présentées ci-dessous :

## Travail en atelier

Pour l’entièreté des travaux en atelier, dont l’usinage métallique et la soudure, nous étions assistés par Daniel Gebhard, grand-père de Samuel Gebhard, ayant longtemps travaillé comme mécanicien agricole. Sur les conseils de Daniel Gebhard, nous avons accordé de l’importance à l’utilisation correcte des machines comme le tour à métaux ou encore la perceuse à colonne. Les mesures de sécurité les plus évidentes,telles que le port de lunettes de soudure, ont évidemment été appliquées avec soin.

## Dangers pour la santé

Nous avons été amenés à utiliser à plusieurs reprises, dans le cadre de l’impression 3D, des matériaux pouvant être dangereux pour la santé tels que l’acétone, l’ABS ou l’ASA.

### - ASA, ABS

L’ASA (Acrylonitrile styrène acrylate) et l’ABS (Acrylonitrile butadiène styrène) sont tous les deux des polymères thermoplastiques idéaux pour l’impression 3D. Nous les avons utilisés afin d’imprimer les grains de carburants utilisés pendant les tests. L’ASA et l’ABS ne présentent aucun danger à température ambiante²⁴

, mais peuvent porter atteinte à la santé à des températures plus élevées. Lors de l’impression 3D de ces matériaux, les bobines de filament d’ASA et d’ABS sont chauffées à leur température de fusion, soit environ 250°C, afin de les faire fondre. A cette température, des COV (composés organiques volatils) ou encore des UFP (particules ultrafines)

24 PDF [en ligne]. [s. d.]. [Consulté le 19 juillet 2024]. Disponible à l’adresse : https://printparts.com/datasheets/ABS-MSDS.pdf. PDF [en ligne]. [s. d.]. [Consulté le 19 juillet 2024]. Disponible à l’adresse : https://printparts.com/datasheets/ABS-MSDS.pdf.

Figure 21: Pictogrammes de dangers rencontrés dans ce travail -https://www.anmeldestelle.admin.ch/chem/fr/home/themen/pflicht-hersteller/selbstkontrolle/kennzeichnung/gefahrenpiktogramme.html.

2024 | 29 | Gymnase de Morges

sont émises.²⁵ Ces particules - parfois de taille inférieure à 0,1 μm - peuvent pénétrer dans les poumons pouvant ainsi exposer les acteurs concernés à des maladies cardiaques ou pulmonaires²⁶. Afin de minimiser l’exposition à ces particules, nos imprimantes 3D sont placées dans nos caves respectives, dans des lieux constamment aérés et éloignés des lieux de vie.

### - Acétone

L’acétone est un dissolvant liquide incolore, que nous avons utilisé afin de dissoudre de l’ASA ou de l’ABS, pour l’utiliser comme liaison liquide sur nos plateaux d’impression 3D. Une fois chauffés par le plateau de l’imprimante, l’ABS ou l’ASA liquide assurent un meilleur contact entre la pièce imprimée et le plateau d’impression, évitant le décollement des pièces. Ce procédé est plus amplement expliqué dans l’article du site Polyfab3D²⁷. L’acétone est cependant inflammable et peut causer des irritations cutanées. L’inhalation de ces vapeurs peut aussi provoquer des troubles respiratoires²⁸. Lors de son utilisation, nous portions des gants de protection et privilégions les lieux aérés éloignés d’autres personnes ou animaux.

### - PLA et PETG

L’impression de thermoplastiques autres tels que le PLA (Acide poly lactique) ou le PETG (Polyéthylène téréphtalate glycol) peut aussi émettre, en faible quantité, d’autres particules fines. Les mêmes précautions que celles mises en place pour l’ABS et l’ASA ont été également appliquées lors de l’utilisation de ces thermoplastiques.

## Test du moteur

### - Gaz de combustion

Lors de la combustion des blocs d’ASA et d’ABS, de grandes quantités de gaz chauds étaient rejetées du moteur. Parmi ces gaz de combustion, certains composés peuvent être dangereux pour la santé. Sachant qu’il nous était impossible d’obtenir une combustion parfaite, de légères quantités de monoxyde de carbone (CO) pouvant nuire à la santé ont été émises en plus du dioxyde de carbone (CO2). De plus, lors de la combustion, le styrène contenu dans l’ABS et l’ASA

25 DOAN, Minh Cuong. Plastique ABS toxicité. Dans : Alveo3D [en ligne]. 5 mars 2024.
[Consulté le 19 juillet 2024]. Disponible à l’adresse : https://www.alveo3d.com/plastique-abs-toxicite/. DOAN, Minh Cuong. Plastique ABS toxicité. Dans : Alveo3D [en ligne]. 5 mars 2024.
[Consulté le 19 juillet 2024]. Disponible à l’adresse : https://www.alveo3d.com/plastique-abs-toxicite/. 26 Particule ultrafine [en ligne]. [S. l.] : [s. n.], 19 janvier 2024. [Consulté le 19 juillet 2024]. Disponible à l’adresse : https://fr.wikipedia.org/w/index.php?title=Particule_ultrafine&oldid=211645411. Page Version ID: 211645411. Particule ultrafine [en ligne]. [S. l.] : [s. n.], 19 janvier 2024. [Consulté le 19 juillet 2024]. Disponible à l’adresse : https://fr.wikipedia.org/w/index.php?title=Particule_ultrafine&oldid=211645411. Page Version ID: 211645411.
27 JULIETTE. Comment préparer un jus d’ABS pour vos impressions 3D ? Dans : Polyfab3D [en ligne]. 12 juillet 2021. [Consulté le 19 juillet 2024]. Disponible à l’adresse : https://www.polyfab3d.fr/ressources/jus-d-abs-comment-preparer-impression-3d/. JULIETTE. Comment préparer un jus d’ABS pour vos impressions 3D ? Dans : Polyfab3D [en ligne]. 12 juillet 2021.
[Consulté le 19 juillet 2024]. Disponible à l’adresse : https://www.polyfab3d.fr/ressources/jus-d-abs-comment-preparer-impression-3d/.
28 Acétone [en ligne]. [S. l.] : [s. n.], 7 février 2024. [Consulté le 19 juillet 2024]. Disponible à l’adresse : https://fr.wikipedia.org/w/index.php?title=Ac%C3%A9tone&oldid=212242506. Page Version ID: 212242506. Acétone [en ligne]. [S. l.] : [s. n.], 7 février 2024. [Consulté le 19 juillet 2024]. Disponible à l’adresse : https://fr.wikipedia.org/w/index.php?title=Ac%C3%A9tone&oldid=212242506. Page Version ID: 212242506.

2024 | 30 | Gymnase de Morges

se décompose et est libéré dans l’air. Le styrène (C8H8) est un composé organique qui peut, en concentration élevée, occasionner des irritations ainsi que des troubles du système nerveux lors de son inhalation²⁹

### - Gaz à haute pression

Les gaz à l’intérieur de la chambre de combustion pouvant atteindre des pressions importantes, le moteur a été construit à partir de matériaux solides, résistant amplement aux pressions maximales théoriquement atteignables. La bouteille d’oxygène, contentant l’oxygène gazeux servant d’oxydant durant les tests, était aussi hautement pressurisée. Les différentes pièces de la plomberie reliant le moteur à la bonbonne, ainsi que les différents joints d’étanchéité, ont été choisis de sorte à assurer sans dommage les pressions subies.

### - Mesures de sécurité appliquées

Afin d’éviter tous les risques cités précédemment, toutes les mesures de sécurité suivantes ont été appliquées avec précaution lors de chacun des tests du moteur.
- Les tests doivent être effectués en extérieur, dans des endroits aérés.
- Aucun objet inflammable ou non ne doit être situé à l’avant du moteur.
- Le banc de test sur lequel est fixé le moteur doit être solidement attaché au sol.
- Aucune personne ni animal ne doit se trouver dans un périmètre de 3 mètres autour du moteur.
- Si la vanne principale de la bonbonne d’oxygène doit être tournée à la main, la bonbonne est éloignée au maximum du moteur et en aucun cas en direction de la sortie des flammes.
- A la fin du test, les différentes vannes d’oxygène doivent être fermées dans un ordre spécifique, avant même que quelqu’un ne puisse approcher le moteur. Une fois l’entrée d’oxygène coupée, il n’y a plus de risque de combustion intense.
- Les pièces du moteur pouvant être encore extrêmement chaudes longtemps après le test, personne ne doit toucher le moteur dans la minute suivant la fin du test.
- Des procédures de sécurité ont été appliquées avant et après chaque test. Ces procédures sont disponibles en annexe M.
Ces mesures de sécurité ont été longuement réfléchies et nous ont permis d’effectuer notre travail sans risque et en toute sécurité.

# 6.2 Règlementations suisses

Pour des raisons évidentes, l’espace aérien est strictement réglementé en Suisse comme dans tous les états. Cependant, les lois s’appliquant à la discipline de l’astromodélisme ne sont pas explicitement formulées. De ce fait, nous nous réfèrerons aux réglementations s’appliquant pour l’ensemble de l’espace aérien suisse, ainsi que celles concernant l’aéromodélisme (discipline similaire à l’astromodélisme, mais qui utilise des modèles réduits d’avions et non des fusées).

29 Styrène [en ligne]. [S. l.] : [s. n.], 26 avril 2024. [Consulté le 19 juillet 2024]. Disponible à l’adresse : https://fr.wikipedia.org/w/index.php?title=Styr%C3%A8ne&oldid=214590551. Page Version ID: 214590551. Styrène [en ligne]. [S. l.] : [s. n.], 26 avril 2024. [Consulté le 19 juillet 2024]. Disponible à l’adresse : https://fr.wikipedia.org/w/index.php?title=Styr%C3%A8ne&oldid=214590551. Page Version ID: 214590551.

2024 | 31 | Gymnase de Morges

Dans notre cas, notre moteur n’est soumis à aucune réglementation particulière pour sa construction. Cependant, l’utilisation de ce moteur dans une fusée expérimentale, ne serait possible que sous certaines conditions.
Dans l’Ordonnance du DETEC sur les aéronefs de catégories spéciales (OACS) du 24 novembre 2022 (État le 1er août 2024)³⁰, s’appliquant également selon le RÈGLEMENT D'EXÉCUTION (UE) 2019/947 DE LA COMMISSION du 24 mai 2019³¹, nous trouvons les réglementations relatives au «système d'aéronef sans équipage à bord» («UAS») défini comme « tout aéronef sans équipage à bord et l'équipement servant à le contrôler à distance »

32, dont notre potentielle fusée expérimentale ferait partie.
L’utilisation d’UAS est divisée en trois catégories³³;
- La catégorie dite « ouverte » ne nécessitant aucune autorisation est cependant limitée à des vols dits « à vue », où l’engin doit toujours être visible par l’exploitant. Cette catégorie plafonne également l’altitude maximale de 120m au-dessus du sol.
- La catégorie dite « spécifique » nécessitant une autorisation d’exploitation délivrée par une autorité compétente de l’état dans lequel le vol a lieu.
- Et la catégorie dite « certifiée » nécessitant une certification propre à l’UAS ainsi qu’une certification pour l’exploitant.
Étant donné les restrictions d’altitude imposées dans la catégorie ouverte et notre potentielle fusée expérimentale dépassant aisément ce maximum, une autorisation de catégorie spécifique nous serait nécessaire. Il existe également, selon le droit suisse, un âge minimum requis pour l’utilisation d’un UAS, fixé à 12 ans pour la catégorie ouverte et à 14 ans pour la catégorie spécifique³⁴
La restriction d’altitude pour la catégorie ouverte existe dans le but de protéger et d’éviter une intrusion dans l’espace aérien par d’autres aéronefs. Ce plafond est d’ailleurs réduit si on opère à proximité de lieux au trafic aérien plus dense tel que les aérodromes et aéroports. Si nous voulions dépasser ce plafond, il aurait été nécessaire, en plus de l’autorisation de catégorie spécifique, de planifier une fenêtre de tir. Ceci afin de coordonner le trafic aérien en conséquence, ce qui demande des procédures encore plus longues et complexes.
Il nous était alors impossible d’utiliser notre moteur dans une fusée expérimentale sans posséder des autorisations particulières. Ces certifications étant difficiles à obtenir, notre travail s’est focalisé sur la construction du moteur et son processus de test au sol. Notre but était ainsi de

30 RS 748.941 - Ordonnance du DETEC du 24 novembre 2022 sur ... [en ligne]. [s. d.].
[Consulté le 14 août 2024]. Disponible à l’adresse : https://www.fedlex.admin.ch/eli/cc/2022/802/fr. RS 748.941 - Ordonnance du DETEC du 24 novembre 2022 sur ... [en ligne]. [s. d.].
[Consulté le 14 août 2024]. Disponible à l’adresse : https://www.fedlex.admin.ch/eli/cc/2022/802/fr.
31

RÈGLEMENT D’EXÉCUTION (UE) 2019/ 947 DE LA COMMISSION - du 24 mai 2019 - concernant les règles et procédures applicables à l’exploitation d’aéronefs sans équipage à bord. [s. d.]. RÈGLEMENT D’EXÉCUTION (UE) 2019/ 947 DE LA COMMISSION - du 24 mai 2019 - concernant les règles et procédures applicables à l’exploitation d’aéronefs sans équipage à bord. [s. d.].
32 Article 2, point 1) du RÈGLEMENT D'EXÉCUTION (UE) 2019/947 DE LA COMMISSION du 24 mai 2019 33 Article 3, alinéas a),b) et c) du RÈGLEMENT D'EXÉCUTION (UE) 2019/947 DE LA COMMISSION du 24 mai 2019
34 Section 3, article 26, alinéas a. et b. de l’Ordonnance du DETEC sur les aéronefs de catégories spéciales (OACS) du 24 novembre 2022 (État le 1er août 2024)

2024 | 32 | Gymnase de Morges

prouver théoriquement la viabilité de notre moteur dans une fusée expérimentale. Nous voudrions tout de même continuer ce projet dans le futur et espérons pouvoir, un jour, voir décoller notre fusée.
L’une des meilleures alternatives aux procédures citées ci-dessus, est l’intégration dans une association d’aéromodélisme ou d’astromodélisme. Ces dernières offrent la possibilité, lors de journées planifiées, de tirer des fusées expérimentales en toute sécurité dans un espace aérien préalablement restreint. Cependant, ces associations requièrent pour la plupart la majorité de l’exploitant s’il veut participer à des tirs de fusées. Ces associations permettent aussi d’obtenir des certifications individuelles ou encore de faire certifier un moteur artisanal, afin de l’utiliser de manière sécurisée. L’une des principales associations de ce type est Tripoli Rocketry Association.

# 6.3 Tripoli Rocketry Association

Tripoli³⁵ est une association d’astromodélisme mondiale fondée en 1964. L'association a pour but de fournir un cadre sécurisé et réglementé pour les amateurs de fusées permettant de pratiquer l’astromodélisme à haut niveau.
Elle organise dans le monde entier des journées de lancement de fusées permettant aux particuliers de lancer leurs fusées dans de bonnes conditions.
Par sa renommée mondiale, de nombreuses filiales ont vu le jour, augmentant donc le nombre d’adhérents. Par cette association, il devient possible d’obtenir facilement les autorisations pour lancer des fusées supersoniques ou à haute altitude. Elle garantit au travers de certifications similaires à un permis de conduire pour fusées que les engins créés et lancés le sont par des personnes ayant déjà au moins réussi un lancement « parfait » dans la catégorie correspondante. Tripoli divise les fusées en deux grandes catégories :
1. Les « Model Rocket » qui se traduisent par fusées de modélisme, il n’est pas nécessaire d’avoir une certification Tripoli pour pouvoir les lancer, cependant elles doivent respecter les conditions suivantes³⁶ :
a. N’utilise pas plus de 125 grammes de propergol
b. Utilise un propulseur à combustion lente
c. Est fait de papier, de bois ou de plastique cassant
d. Ne contient aucune pièce métallique substantielle
e. Ne pèse pas plus de 1500 grammes, moteur compris
2. Les « High Power Rocket » qui se traduisent par fusée à haute puissance. Ce sont toutes les fusées qui n’entrent pas dans la catégorie des fusées de modélisme. Elles sont limitées à 49’960N d’impulsion totale. Ce qui représente un grand écart entre ces deux

35 Home - Tripoli Rocketry Association [en ligne]. [s. d.]. [Consulté le 30 août 2024]. Disponible à l’adresse : https://www.tripoli.org/.
36 Tripoli Rocketry Association Safety Code. Dans : Tripoli Rocketery Association INC. [en ligne]. [s. d.]. [Consulté le 30 août 2024]. Disponible à l’adresse : https://www.tripoli.org/content.aspx?page_id=22&club_id=795696&module_id=520420.

2024 | 33 | Gymnase de Morges

définitions. C’est pourquoi cette catégorie est divisée en trois certifications attestant du savoir-faire de la personne.

## Les Certifications :

### 1. Niveau 1 (L1) :

- Ce niveau est destiné aux débutants en haute puissance.
- Le détenteur doit être âgé d’au moins 18 ans.
- Les membres doivent démontrer leur capacité à lancer et récupérer une fusée propulsée par un moteur de classe H ou I.
- Le but est de s'assurer que le membre comprend les bases de la sécurité, de la construction de fusées et des techniques de lancement.

### 2. Niveau 2 (L2) :

- Ce niveau est destiné aux membres plus expérimentés et détenteurs de la certification L1.
- Les candidats doivent lancer une fusée propulsée par un moteur de classe J, K ou L.
- En plus du lancement, les membres doivent passer un examen écrit qui teste leurs connaissances théoriques en aérodynamique, en balistique, et en sécurité.
- Ce niveau permet de certifier des moteurs expérimentaux et de lancer des fusées les contenant, ce qui est le cas de notre moteur si nous construisons un exemplaire qui serait adapté au vol.

### 3. Niveau 3 (L3) :

- Le niveau 3 est destiné aux experts en fuséologie détenteurs du niveau L2.
- Les membres doivent lancer une fusée propulsée par un moteur de classe M, N, ou O.
- Une documentation complète du projet, comprenant la conception de la fusée, les calculs aérodynamiques et une évaluation des risques, doit être soumise et approuvée par un comité de certification.
- Le lancement doit être supervisé par des représentants de Tripoli pour garantir que toutes les normes de sécurité sont respectées.

# 7.Version Initiale V1

# 7.1 Etude générale

Voici la liste des questions et de leurs réponses qui ont servi à notre étude générale.

### - Quels sont les objectifs de notre moteur ?

- Le prototype devait être fonctionnel, fiable, modifiable, réutilisable et capable de théoriquement propulser un modèle réduit de fusée. Il devait produire une poussée notable et garantir le succès des tests dans la plage de fonctionnement finale. Conçu pour l'expérimentation, il intégrait des capteurs et des pièces interchangeables, sans viser une optimisation de masse ni un format adapté au vol.

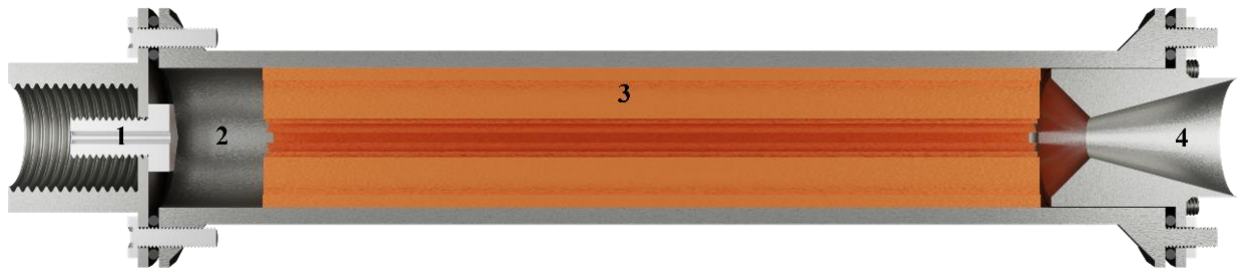
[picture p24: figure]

2024 | 34 | Gymnase de Morges
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

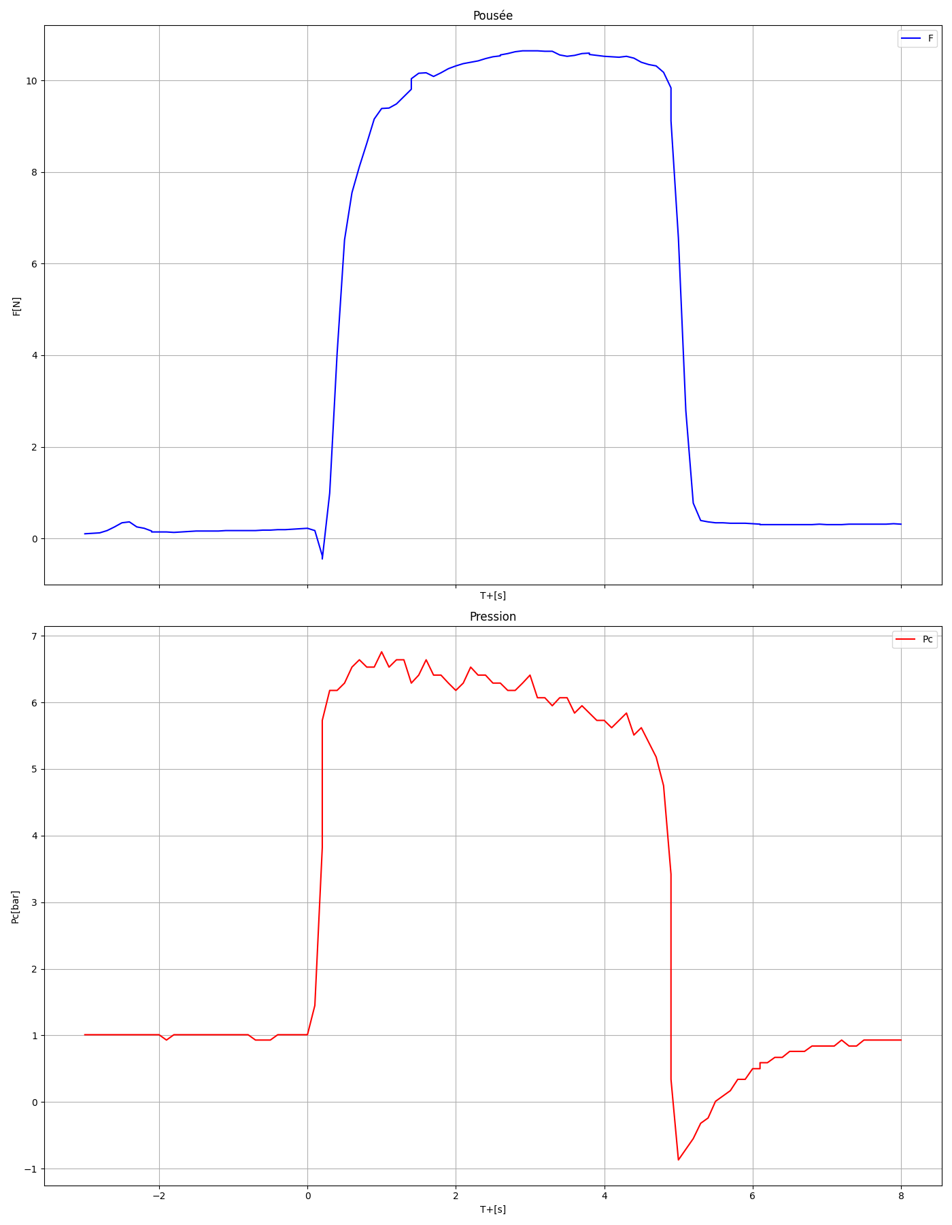
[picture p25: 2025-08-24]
docs/v3/v3-1/v3-1-1/v3-1-1.png

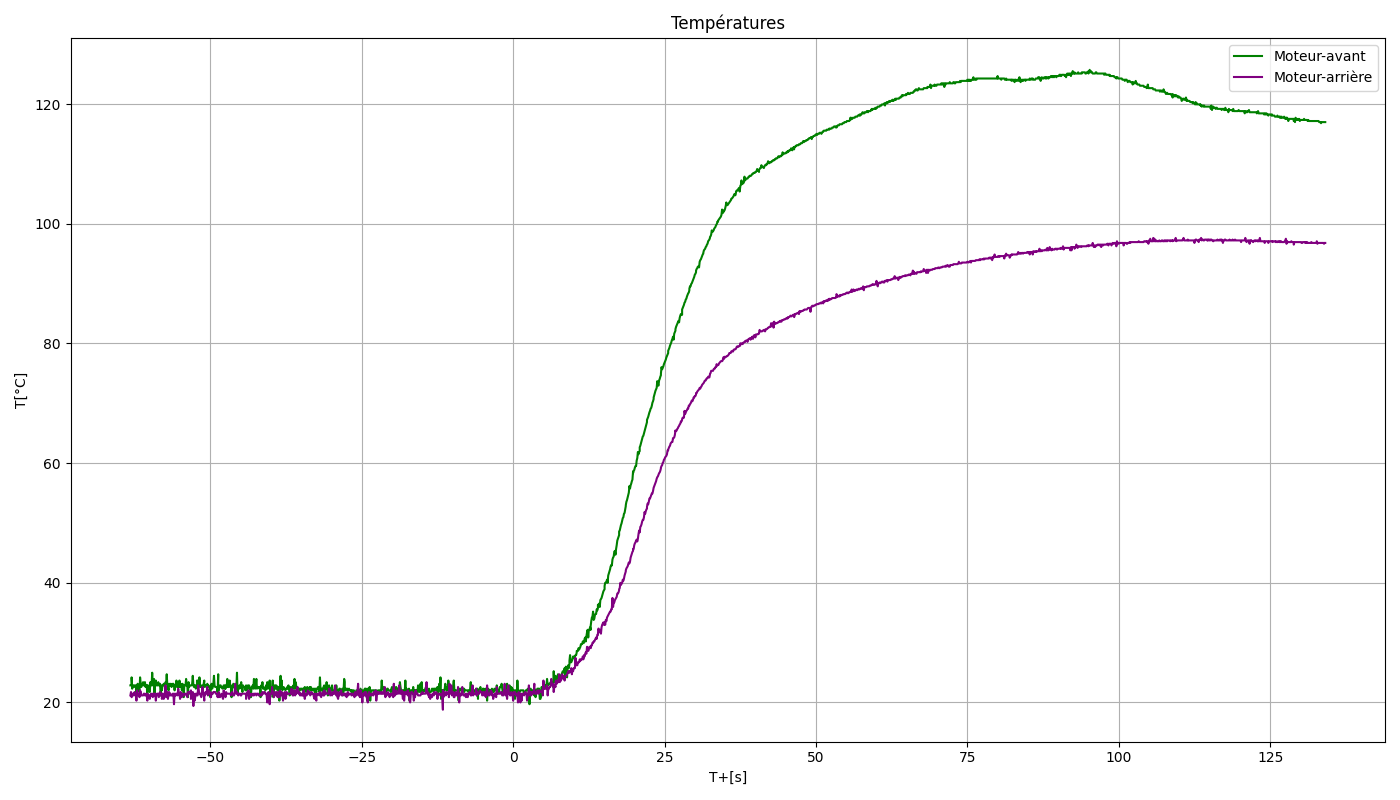
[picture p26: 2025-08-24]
docs/v3/v3-1/v3-1-2/v3-1-2-temp.png

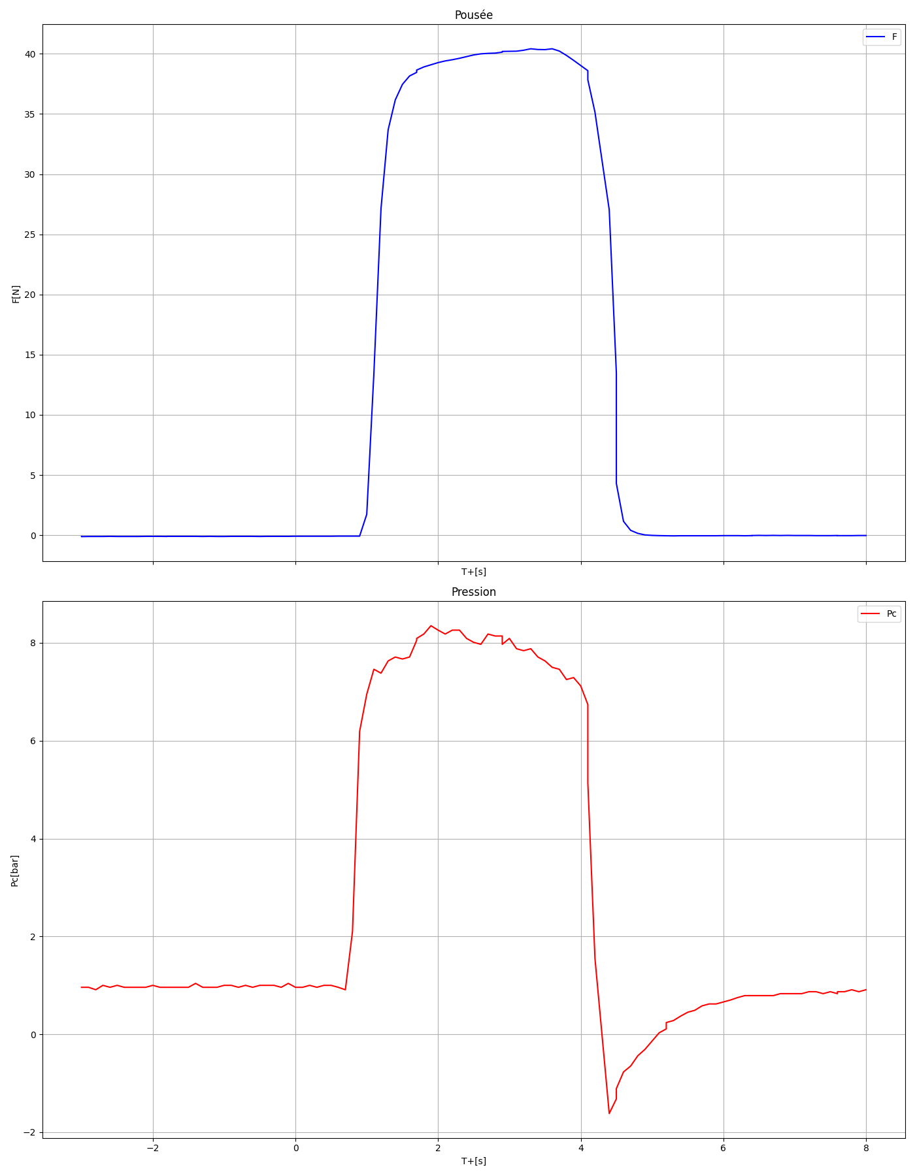
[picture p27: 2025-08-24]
docs/v3/v3-3/v3-3-1.png

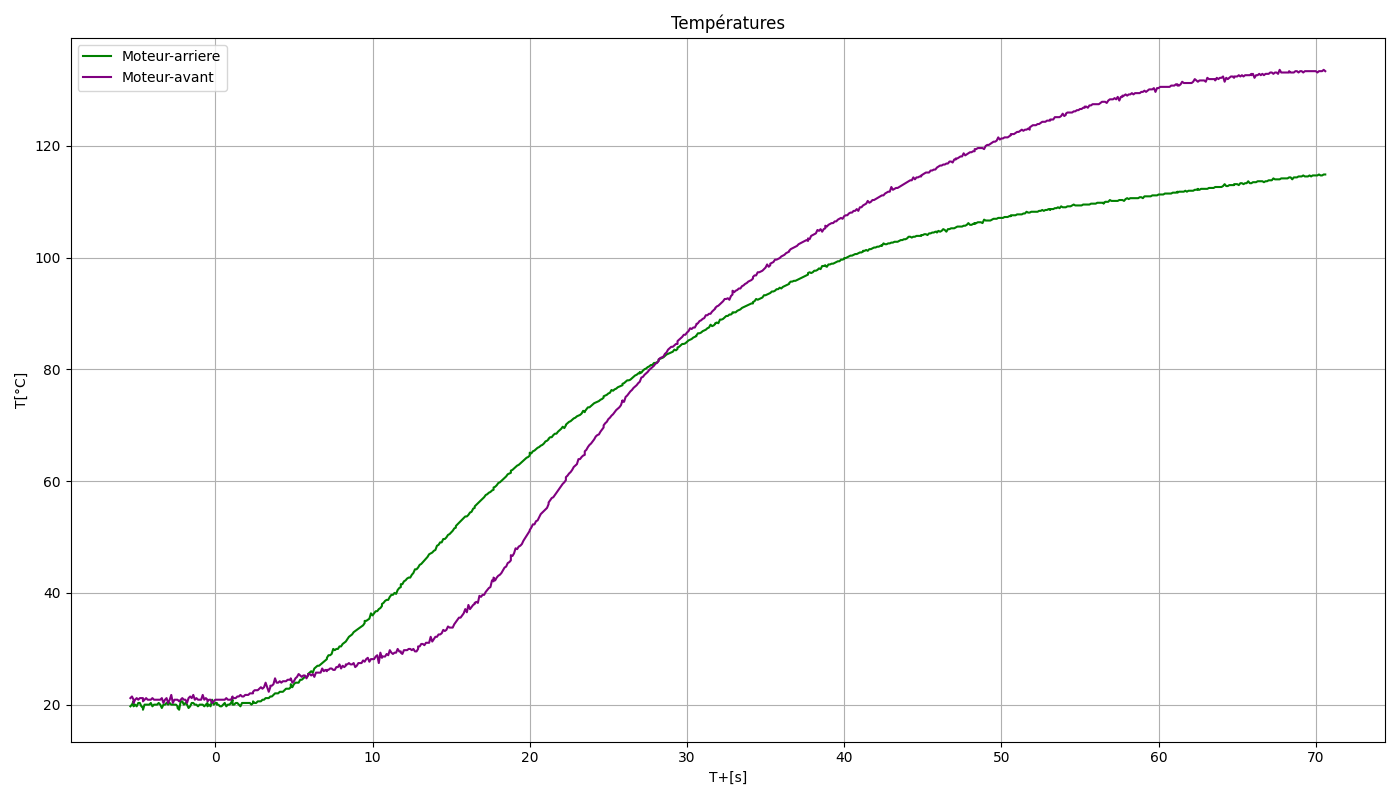
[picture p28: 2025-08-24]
docs/v3/v3-2/v3-2-1-temp.png

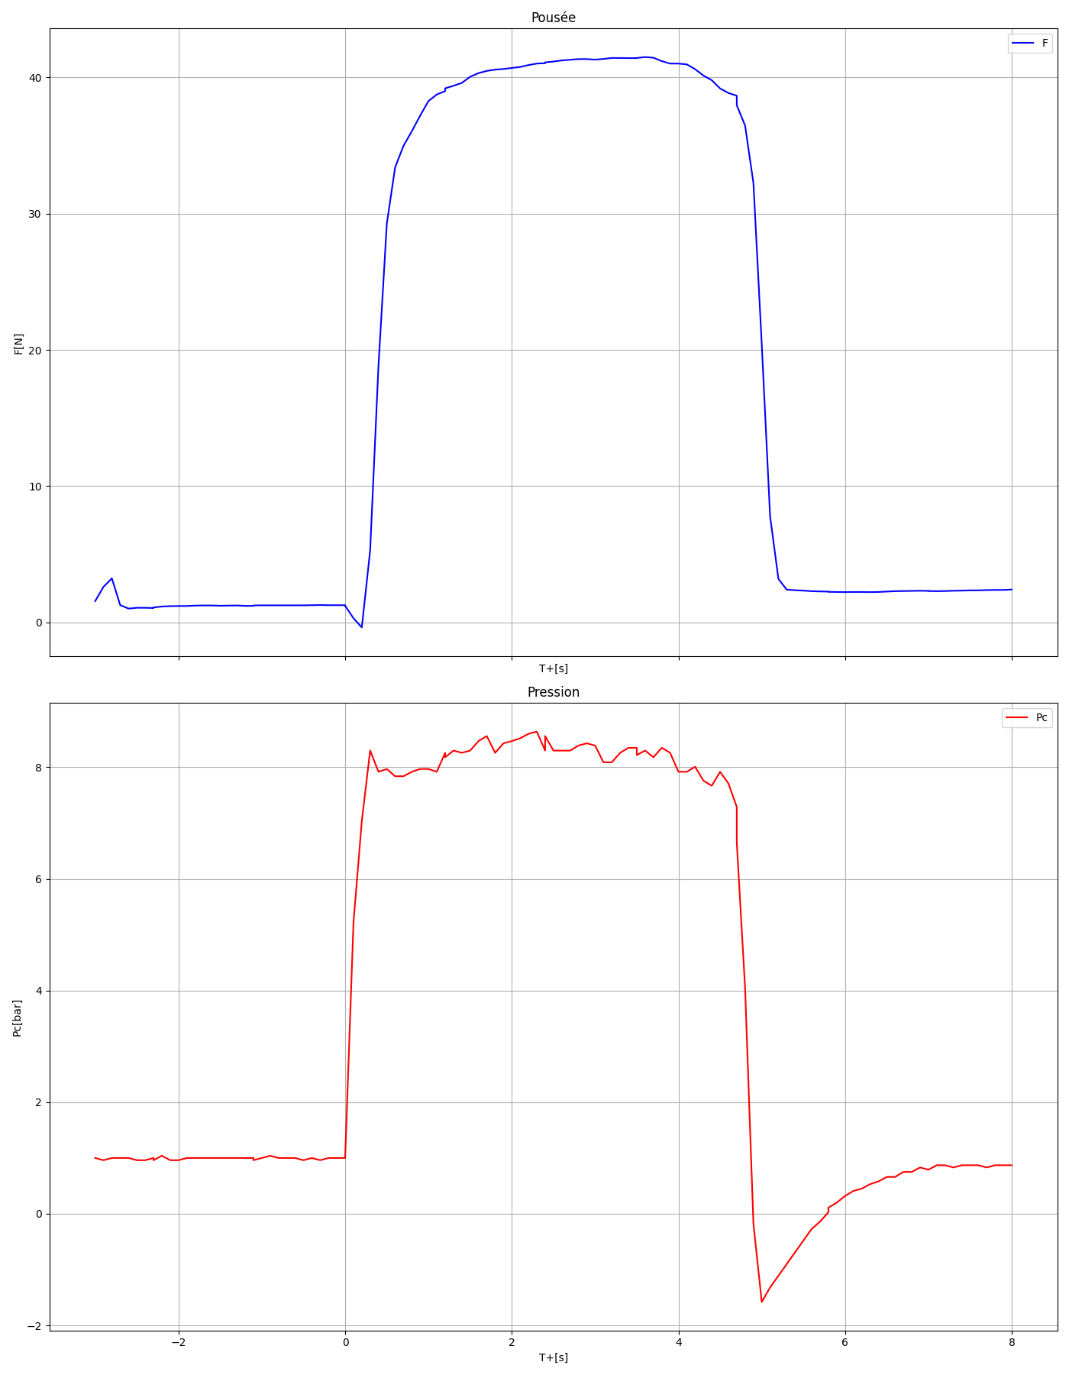
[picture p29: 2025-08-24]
docs/v3/v3-1/v3-1-2/v3-1-2.png

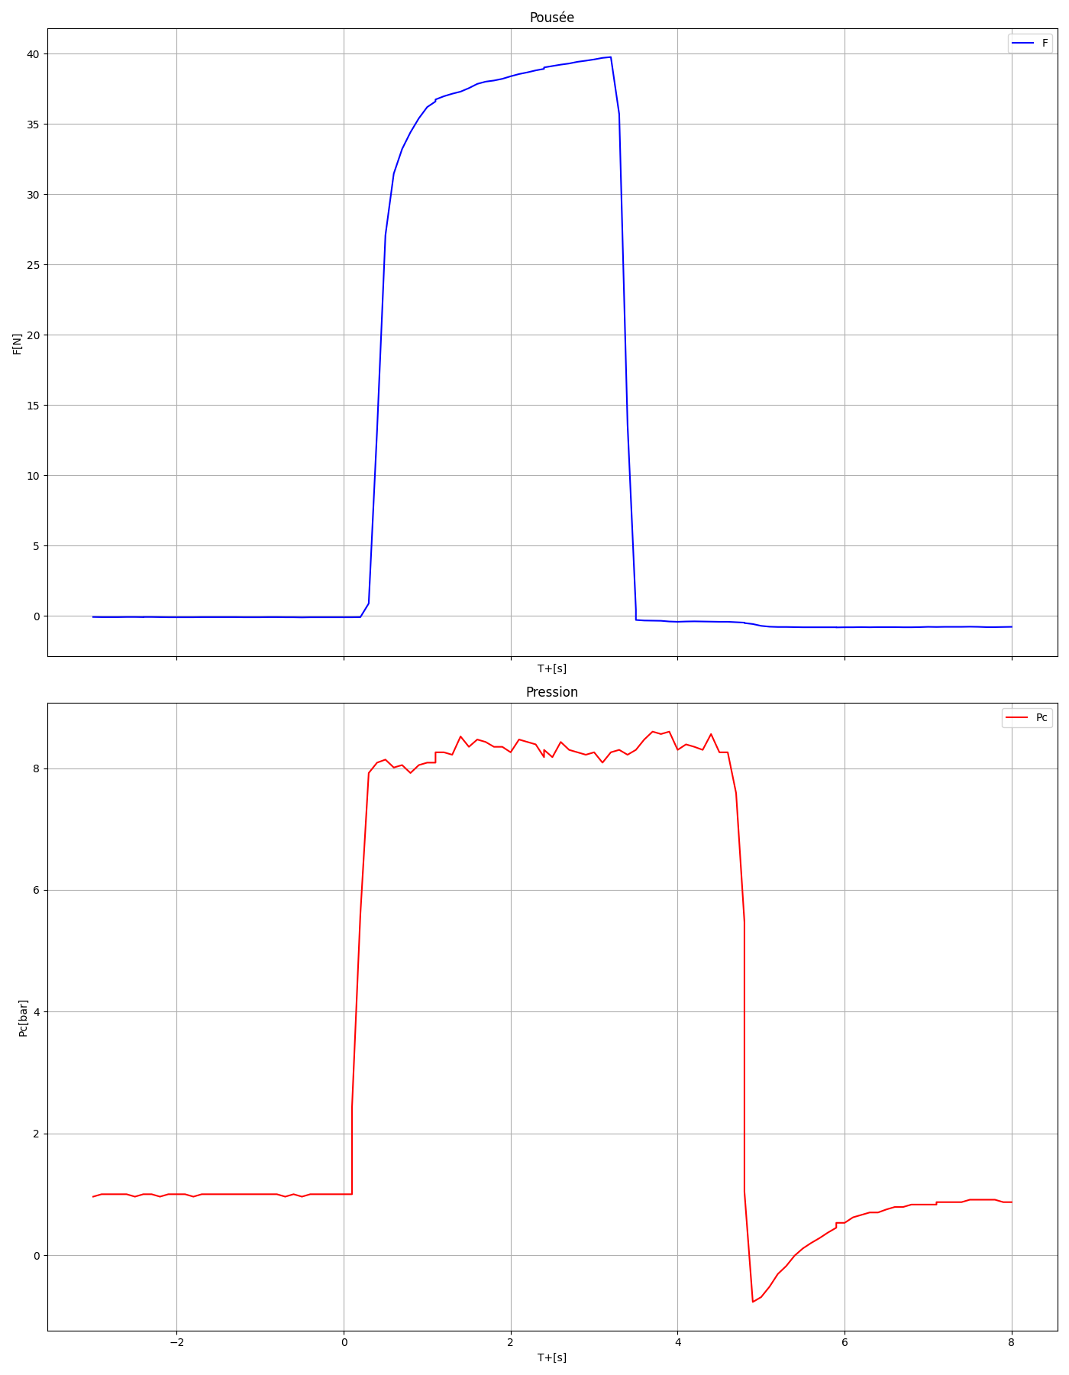
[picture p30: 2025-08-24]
docs/v3/v3-2/v3-2-1.png

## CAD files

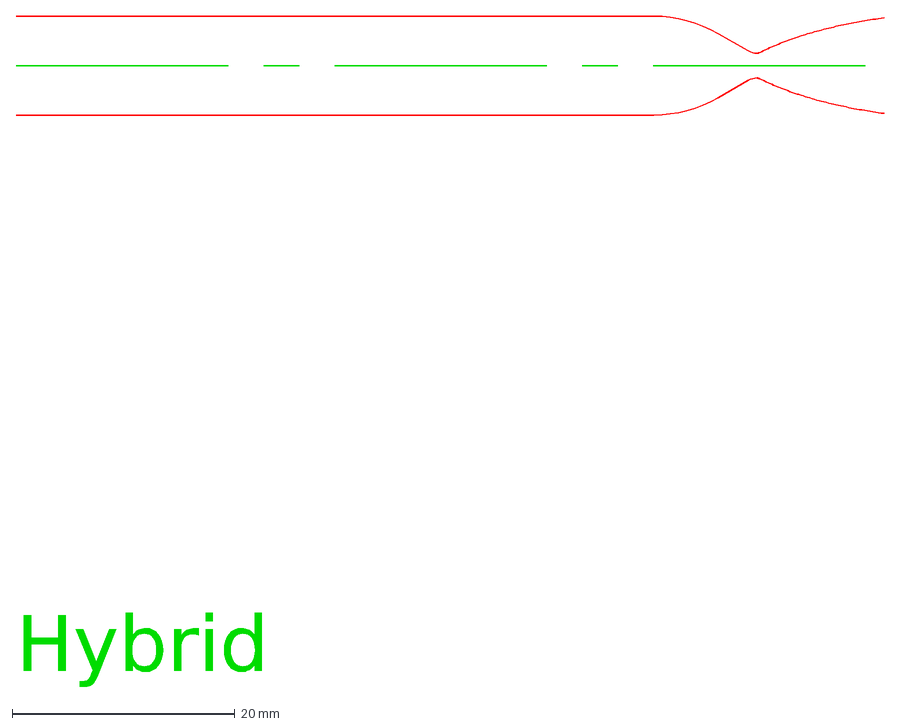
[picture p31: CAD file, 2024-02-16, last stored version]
nozzle v1.dxf
Hybrid

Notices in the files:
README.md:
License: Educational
